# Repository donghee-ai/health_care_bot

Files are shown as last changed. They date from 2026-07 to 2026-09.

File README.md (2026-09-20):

# health_care_bot — UNO Q Health Coach Robot

> 한국어: [`README.md`](README.md)

A health coach robot running as a **single Docker container, single process** on an
Arduino UNO Q (Qualcomm Dragonwing QRB2210, quad-core Cortex-A53 + STM32U585).

It watches your posture through a camera and **counts your reps**, **follows you with a
PTZ gimbal**, and **serves the mobile web app** — all from the same process.

<table>
<tr>
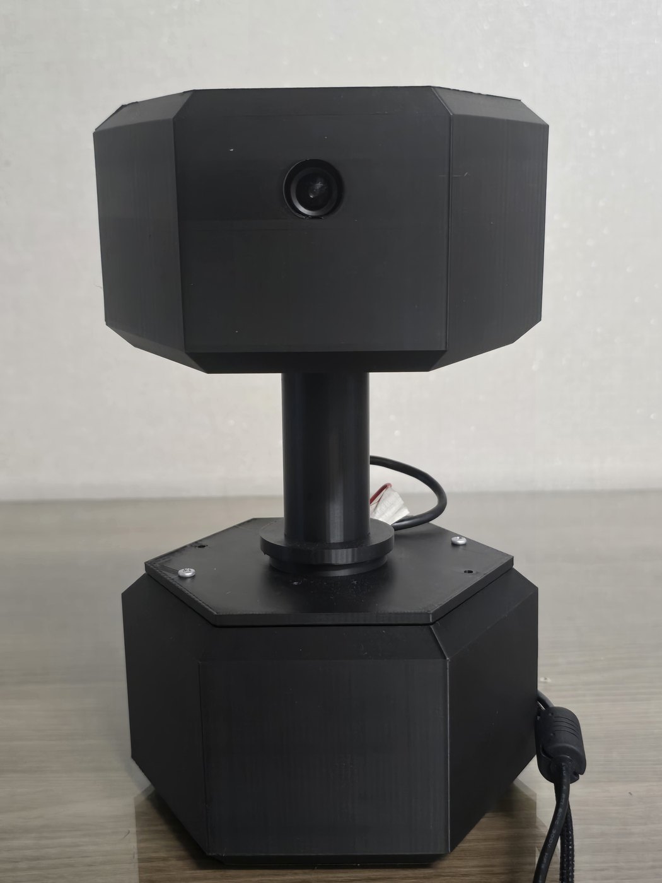
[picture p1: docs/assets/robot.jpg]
The gimbal housing — head holding the camera and pitch motor, hexagonal base holding the yaw motor
<td colspan="2" align="center"><br>
<sub><b>Gimbal housing v8.43</b> · <b>Head</b>: camera + pitch motor (ID=2) · <b>Base</b>: yaw motor (ID=1) + UNO Q, powered hub, servo adapter<br>Both servos sit on one daisy-chained bus</sub></td>
</tr>
<tr>
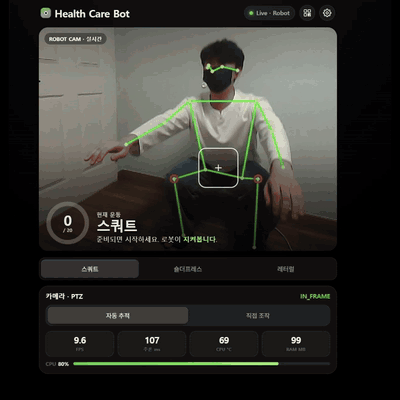
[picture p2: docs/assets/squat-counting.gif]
Squat counting
<td width="50%"><br>
<sub><b>Squat</b> — knee angle 100°↔140° · counter 0→3</sub></td>
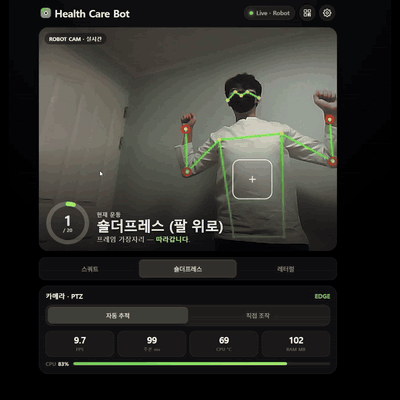
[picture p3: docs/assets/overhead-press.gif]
Overhead press counting
<td width="50%"><br>
<sub><b>Overhead press</b> — shoulder elevation 60°↔140° · 1→3</sub></td>
</tr>
<tr>
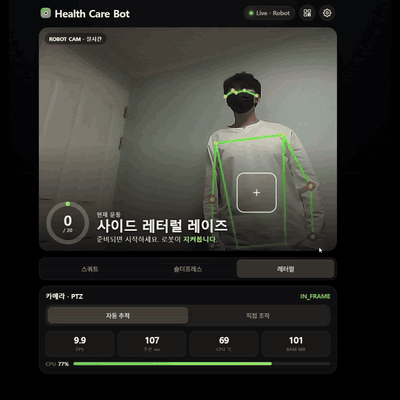
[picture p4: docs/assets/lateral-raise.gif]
Side lateral raise counting
<td width="50%"><br>
<sub><b>Side lateral raise</b> — same angle, 35°↔80° · 0→2</sub></td>
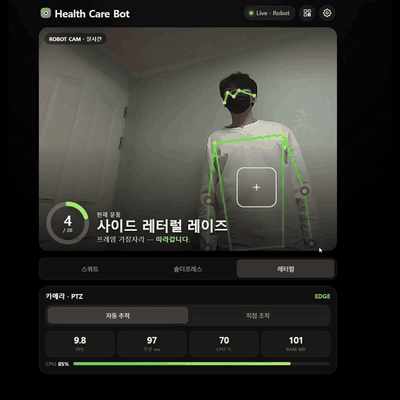
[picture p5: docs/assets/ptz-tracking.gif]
PTZ auto-tracking
<td width="50%"><br>
<sub><b>PTZ auto-tracking</b> — the gimbal pans to follow (watch the background change) · reacquires after the subject leaves frame · <code>EDGE</code>↔<code>IN_FRAME</code></sub></td>
</tr>
<tr>
<td colspan="2"><sub>All four are screen recordings of <code>:8080/app</code> with <b>no speed-up</b> — every 4th frame of a 30 fps capture, played at 7.5 fps, which is real time.
The <b>9.7 FPS · 96 ms · 69 °C · CPU 84 %</b> visible on screen are the live measurements from that moment, matching the table in §9.</sub></td>
</tr>
</table>

> **Documentation note** — This README is the entry point. The detail lives in
> `docs/00`–`docs/09`, **written in Korean**. Their tables, numbers, API schemas and
> command lines are readable without Korean, and the section numbers cited here match.

> **Sister repo** — The MoveNet Thunder INT8 model this robot uses came from
> [`donghee-ai/unoq-edge-ai-lines`](https://github.com/donghee-ai/unoq-edge-ai-lines),
> which measured Vision · Pose · ASR on the same NPU-less UNO Q using CPU only. This repo
> is the product line built from its Pose assets.

---

## 1. What actually runs

| # | Feature | Implementation | Status |
|---|---|---|---|
| 1 | **Squat** counting | knee angle hip-knee-ankle, hysteresis 100°↔140° | works (thresholds still need field tuning) |
| 2 | **Overhead press** counting | shoulder elevation elbow-shoulder-hip, 60°↔140° | works (same) |
| 3 | **Side lateral raise** counting | same shoulder elevation angle, 35°↔80° | works (same) |
| 4 | **PTZ auto-tracking** | two ST3215 bus servos, per-exercise upper/lower-body framing + inertial recovery on loss | verified on hardware |
| 5 | **Web app** (`:8080/app`) | live MJPEG + counters + PTZ control + telemetry | verified on hardware |
| 6 | **Guard mode** | a fourth mode, separate from exercise. Homes immediately on entry → arms after 5 s → on person detection, tracks and captures automatically (`captures/`) → returns home after 10 s with no detection. Manual capture and a photo gallery are available from the web UI | verified on hardware |
| 7 | **Remote access** (Tailscale Funnel) | reach `/app` from outside the local Wi-Fi | verified on hardware (§3.2) |

**Exercises are not classified automatically.** All three are performed facing the camera
while standing, so body orientation cannot separate them — you pick the exercise in the web
UI (`POST /api/mode`). All three counters stay alive simultaneously, so switching modes
preserves each count.

> Push-ups were **removed** on 2026-07-26 — the arms bend along the camera's depth axis, so
> a 2D pose estimator smears the elbow angle. Rationale:
> [`docs/04_algorithm_exercise.md`](docs/04_algorithm_exercise.md) §7.

---

## 2. Architecture at a glance

```
[USB camera] --(FrameGrabber on its own thread: keeps only the newest frame)-->
      |
      v
[MoveNet Thunder INT8 / ai-edge-litert, 256x256 letterbox, 4 threads]
      |
      +--> 17 keypoints (y, x, conf)
             |
             +--> angles.py        knee / shoulder-elevation angles
             |      v
             |    exercise_counter.py   RepCounter (hysteresis + dwell) --> rep++
             |
             +--> ptz_controller.py  target point -> sector/deadzone decision -> deg/s control
             |      v
             |    st3215_bus.py (pyserial, 1 Mbaud, half-duplex)
             |      v
             |    [Bus Servo Adapter] -> [yaw ST3215 ID=1] -> [pitch ID=2]  (daisy chain)
             |
             +--> http_server.py   MJPEG + stats.json + /api/* + /app static serving
                    v
                  browser at http://<UNO_Q_IP>:8080/app
```

**Linux drives the servos directly — not through the MCU.** The ST3215 bus servo adapter
hangs off a USB hub on the UNO Q, and Linux (pyserial) talks to it. `ptz/sketch/health_care_ptz.ino`
is a leftover from the earlier MCU-mediated design and **is not used at runtime.**

Detail: [`docs/01_architecture.md`](docs/01_architecture.md)

---

## 3. Quick start

### 3.1 On the device (UNO Q) — normal operation

```bash
ssh arduino@192.168.0.50              # private LAN; get credentials from the device
cd ~/health_care_bot
bash docker/run.sh                    # auto-detects camera/servo nodes and starts
```

Open `http://192.168.0.50:8080/app` — PTZ control works immediately (control is shared).

Stop with `docker stop health-care-bot`.

> **Check before running** — `/dev/videoN` and `/dev/ttyACM*` numbers **change on every
> boot.** `run.sh` finds them by name, but always read the `camera:` / `serial:` lines in
> the startup log. Override manually with `CAMERA_DEV=/dev/video2 bash docker/run.sh`.
>
> **The IP is DHCP and can change when the router reboots** (it actually moved `.45`→`.50`
> on 2026-08-08). If it does not respond, rescan with `arp -a` or a ping sweep. See
> [`08_troubleshooting.md`](docs/08_troubleshooting.md).

### 3.2 Remote access — from outside the local Wi-Fi (Tailscale Funnel)

Set it up once; afterwards `docker/run.sh` alone opens remote access.

```bash
# once — install Tailscale on the device and log in
curl -fsSL https://tailscale.com/install.sh | sh
sudo tailscale up                     # open the printed URL on a phone/PC to authenticate

# only when needed — turn the public URL on/off (both need sudo; run over SSH)
sudo tailscale funnel --bg 8080
sudo tailscale funnel --https=443 off   # always turn this off when the demo ends
```

External URL: `https://<device>.<tailnet>.ts.net/app` — find the real address with
`tailscale status` on the device (not written here; this repo is public).
Between Tailscale devices without Funnel, use the UNO Q's Tailscale IP (`tailscale ip -4`).

> **This app has no real authentication beyond one PIN (default `1234`).** While Funnel is
> on, anyone with the link can see the camera, drive the PTZ, and browse guard-mode
> photos — use it only while showing a demo, and never leave it exposed.
>
> **FPS drops as stream viewers accumulate** — ~11.3 FPS with no viewer, ~10 with one, down
> to ~8 with two (e.g. PC + phone), measured. The cause is Python GIL thread contention plus
> encryption overhead when remote. The practical mitigation is lowering `--jpeg-quality`.

### 3.3 Development PC — servo test over direct serial

```powershell
cd C:\Project\health_care_bot

# full run (web app + counting + PTZ)
py -3.14 src/main.py models/movenet_thunder_int8.tflite --camera 0 --serial COM9 --serve 8080

# PTZ tracking alone (OpenCV window)
py -3.14 scripts/ptz_camera_track.py --port COM9 --camera 0 --drive
```

**Use `py -3.14`** — the Anaconda `base` environment on this PC has no `cv2`. The servo port
is **COM9** (CH343, 1,000,000 baud), and **without external servo power (6–12.6 V) the port
opens but every ID stays silent.**

### 3.4 Model setup — usually unnecessary

`models/movenet_thunder_int8.tflite` (7.1 MB) is **committed to this repo**, so a clone has
it already. You only need the script below when refreshing the model from the sister repo.

```bash
bash scripts/copy_model.sh    # ../unoq-companion-robot/pose/models/ -> models/
```

---

## 4. Layout

```
health_care_bot/
├── README.md / README_en.md    entry point (Korean / English)
├── THIRD_PARTY.md              third-party attribution (fonts, model, protocol)
├── src/                        runtime (what the container executes)
│   ├── main.py                 entry point: loop + CLI + telemetry
│   ├── pose_utils.py           keypoint constants / letterbox / centroid helpers / draw
│   ├── angles.py               knee_angle, shoulder_elev_angle, pick_angle
│   ├── exercise_counter.py     RepCounter + Squat/OverheadPress/LateralRaise
│   ├── ptz_controller.py       PTZ tracking + loss recovery + direct servo control
│   ├── st3215_bus.py           low-level ST3215 protocol driver
│   ├── http_server.py          MJPEG + stats.json + /api/* + /app + /captures/*
│   ├── app_state.py            session state + operator PIN control lock + guard state
│   └── guard_capture.py        guard mode: person decision + JPEG write + log
├── captures/                   guard-mode output (jpg + guard_log.jsonl) — gitignored
├── web/
│   ├── app/index.html          ★ the UI served at /app — self-contained, edited directly
│   ├── src/                    Vite + React design studies — archived, not served
│   └── dist/                   build output of the above — gitignored, /app works without it
├── docker/                     Dockerfile · requirements.txt · run.sh
├── models/                     movenet_thunder_int8.tflite
├── scripts/                    benchmarks and tools (not runtime)
├── ptz/sketch/                 MCU sketch — unused (MCU track on hold)
├── 3d_model/                   gimbal housing (source · 3mf · stl · validation · preview)
├── docs/                       see §5
└── backup/                     five restore points
```

---

## 5. Document map

All documents below are in Korean.

| # | Document | Contents |
|---|---|---|
| 00 | [`00_project_blueprint.md`](docs/00_project_blueprint.md) | blueprint — purpose, measured status, verification state, doc map |
| 01 | [`01_architecture.md`](docs/01_architecture.md) | processes/threads, module boundaries, state ownership, degrade paths |
| 02 | [`02_http_api_and_stats.md`](docs/02_http_api_and_stats.md) | HTTP API contract + full `stats.json` schema |
| 03 | [`03_algorithm_ptz_tracking.md`](docs/03_algorithm_ptz_tracking.md) | PTZ control law + inertial loss recovery + tuning |
| 04 | [`04_algorithm_exercise.md`](docs/04_algorithm_exercise.md) | per-exercise angles, counting state machine, failure modes |
| 05 | [`05_web_ui_fluid.md`](docs/05_web_ui_fluid.md) | web UI (Fluid) — screens, controls, deployment |
| 06 | [`06_hardware_calibration.md`](docs/06_hardware_calibration.md) | current hardware values + calibration/reassembly procedure |
| 07 | [`07_runbook.md`](docs/07_runbook.md) | run/deploy runbook (device and PC) |
| 08 | [`08_troubleshooting.md`](docs/08_troubleshooting.md) | symptom → cause index |
| 09 | [`09_performance_roadmap.md`](docs/09_performance_roadmap.md) | measured performance + prioritized next steps |
| — | [`docs/history/`](docs/history/) · [`docs/issues/`](docs/issues/) | append-only records — one event per file |

---

## 6. CLI options (the ones you actually use)

Full list: `python3 src/main.py --help`.

| Flag | Default | Meaning |
|---|---|---|
| `--mode` | `squat` | `squat` / `overhead` / `lateral` / `guard`. Changed live via `/api/mode` |
| `--camera` | `0` | `/dev/videoN` index |
| `--serial` | (none) | servo bus port. **Omitting it degrades to PTZ disabled** |
| `--pitch-sign` / `--yaw-sign` | `-1` / `1` | direction correction after reassembly (fixed 2026-08-06). `docker/run.sh` exposes these as `PITCH_SIGN` / `YAW_SIGN` |
| `--serve` | `0` | HTTP port (0 = off) |
| `--conf` | `0.3` | keypoint confidence threshold |
| `--side` | `better` | left/right angle selection: average if both visible, otherwise the visible one |
| `--squat-down-th` / `--squat-up-th` | 100 / 140 | squat thresholds |
| `--overhead-down-th` / `--overhead-up-th` | 60 / 140 | overhead press thresholds |
| `--lateral-down-th` / `--lateral-up-th` | 35 / 80 | lateral raise thresholds |
| `--min-dwell-ms` | `200` | minimum hold time after a state transition |
| `--idle-skip-draw` | off | skip draw+encode when no stream viewer (compute-focused mode) |
| `--sector-side` | `1/6` | side sector width → keeps a central 4/6 band |
| `--pitch-target-y` / `--pitch-deadzone` | 0.62 / 0.20 | lower-body (squat) framing |
| `--track-scale` / `--both-knee-scale` | 0.5 / 0.5 | tracking speed multipliers (1/4 total when both knees are visible) |
| `--frame-out-grace` | `15` | frames without detection before LOST |

PTZ parameter meanings and tuning: [`docs/03_algorithm_ptz_tracking.md`](docs/03_algorithm_ptz_tracking.md) §11.

---

## 7. Safety and operating rules

- **Never touch servo EEPROM while torque is on.** Changing `Homing_Offset` with torque
  enabled makes the servo physically rotate to its old `Goal_Position` — this mistake has
  already **broken a 3D-printed part**. Always calibrate with
  `scripts/calibrate_st3215.py calibrate`, which handles torque off → recompute → goal sync
  → torque on. Detail: [`docs/issues/2026-07-17_01`](docs/issues/2026-07-17_01_homing_offset_wrong_sign_bit_caused_physical_snap.md)
- **Emergency stop**: from another terminal, `py -3.14 scripts/calibrate_st3215.py --port COM9 stop`
- **Measured range of motion** (2026-07-17): yaw (ID=1) 180° ±90°, pitch (ID=2) 180° ±30°.
  The soft limits in code (`yaw_min/max`, `pitch_min/max`) are exactly these. If you change
  the mechanism, re-measure per [`docs/06_hardware_calibration.md`](docs/06_hardware_calibration.md) §4.
- **Rotation speed is fixed at 569 tick/s (≈50 deg/s)** — including while tracking. This is
  a pinch-safety limit; do not raise it.
- **ST3215 servos all ship with ID 1** — assign yaw=1 / pitch=2 individually before chaining
  them. ID changes take effect **immediately** (unlike the generic SDK docs claiming a power
  cycle is needed): [`docs/issues/2026-07-16_01`](docs/issues/2026-07-16_01_servo_id_change_takes_effect_immediately.md)
- **HTTP has no authentication.** Only operator mutations are gated by a PIN-based control
  lock; reads and the stream are unauthenticated. **Do not expose beyond the local LAN.**
  The default PIN is `1234` and can be changed **without editing code** via the
  `HCB_OPERATOR_PIN` environment variable (`docker/run.sh` passes it through):
  `HCB_OPERATOR_PIN=8317 bash docker/run.sh`. When changed, `/app` asks for the PIN once and
  remembers it in the browser. **Tailscale Funnel (§3.2) is no exception to this rule.**
- **The UNO Q's USB host VBUS is off** — bus-powered hubs and devices are not enumerated.
  A **self-powered (externally powered) USB hub is mandatory.** If the camera *and* the servo
  are both missing, suspect hub power before the individual devices.

---

## 8. Traps we keep stepping on

| Trap | Summary |
|---|---|
| Device node numbers | `/dev/videoN` and `ttyACM/ttyUSB` change on every boot. Identify **by name**, never hard-code a number |
| argparse ↔ run.sh drift | Changing `--mode` choices means updating the hard-coded args in `run.sh` **and the Dockerfile CMD**. `--rm` means nothing survives in `docker logs` |
| Phone cannot connect | `ERR_ADDRESS_UNREACHABLE` means the phone's **randomized MAC**, not a server fault |
| `cv2.CAP_PROP_BUFFERSIZE` | The driver ignores it. Solved with `FrameGrabber` (newest frame only) |
| `adb push` | Git Bash rewrites paths and fails silently → **use PowerShell**. `rm -rf` the remote directory first, or you get nested `src/src/` |
| cp949 console crash | Using characters like em-dash or ⚠ **in code or comments** raises `UnicodeEncodeError` on a Windows console |
| Hard-coded API port in the frontend | Pinning `location.hostname:8080` breaks every request behind a reverse proxy or tunnel (Tailscale Funnel does not use port 8080 externally). Use `location.origin` |
| Static QR image for mobile access | The IP is DHCP, so a pre-rendered QR never updates. Re-encode from `location` in the browser every time (`qrSvg()`) |
| `docker/run.sh` dying silently without a tty | `-it` was hard-coded, so non-interactive SSH failed instantly with `the input device is not a TTY` (and `--rm` left no log). Now detects tty and applies it conditionally |
| "PC works, only the phone fails" is not proof against wireless isolation | If the PC is actually on Ethernet it never hits client isolation in the first place. Check the real route first (`Find-NetRoute` on Windows) |
| Automatic and manual triggers sharing a cooldown | The guard-mode "capture now" button shared the auto-detection cooldown, so it was silently swallowed while a person stayed in frame. Manual triggers now ignore the cooldown |
| Docker images filling the ROOT partition | `/var/lib/docker` lives on ROOT, so repeated rebuilds pile up unused layers. Reclaim with `docker image prune -a` (check the list first — it can remove other projects' images) |

Full index: [`docs/08_troubleshooting.md`](docs/08_troubleshooting.md).

---

## 9. Performance (measured)

| Item | Value | Note |
|---|---|---|
| Inference FPS | ~11.4 | **invoke-bound**. Encoding on/off makes almost no difference (with no viewer) |
| Loop latency | ~90 ms | grab → invoke → draw → encode, serial |
| 1 concurrent viewer | ~10 FPS | one extra delivery thread → GIL contention (local or remote alike) |
| 2 concurrent viewers (PC + phone) | ~8 FPS | thread contention, plus Tailscale encryption when remote |
| CPU | ~83 % (of 4 cores = 100 %) | already in the warning band, 17 % left |
| CPU clock | 2016 MHz on all cores = maximum | no governor headroom left |
| Temperature | 51–73 °C | below throttle |

The only large lever for FPS is an **NPU/DSP delegate** (Hexagon HTP · QNN/LiteRT) — this
CPU lacks `asimddp` (INT8 dot product), so it cannot use fast INT8 kernels.

---

## 10. Model / third-party assets

> **This repo's own license is not decided yet.** While there is no LICENSE file, copyright
> remains with the author (no permission granted for redistribution or commercial use).

- Inference model: **MoveNet Thunder INT8** (`models/movenet_thunder_int8.tflite`, 7.1 MB) —
  reused from the Pose line. **Committed to the repo**, so a clone can run immediately.
- Typefaces (Pretendard, Gabarito) are **SIL OFL 1.1**, and the license copies OFL requires
  are bundled under `web/public/fonts/licenses/`.

**The full list of third-party work redistributed here, with the attribution each license
requires, is in [`THIRD_PARTY.md`](THIRD_PARTY.md).**

---

**Author**: DongHee Kim (Hansung University)

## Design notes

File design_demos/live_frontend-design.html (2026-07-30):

UNO·Q HEALTH CARE BOTFIELD OPTICS

Connecting

00:00:00

CAM 01 · FOV 60°

PAN +000.0°
TILT +00.0°
ACQUIRING…

▶ 카메라 시야 열기

AUTO SQUAT PUSH-UP

현재 감지 · Tracking rep

SQUAT

0/ 20

Auto-trackLOCKED

Servo pan/tilt0.0 / 0.0

Track state—

Inference— FPS

>>

로봇에 연결하는 중…

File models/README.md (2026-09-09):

# models/

추론 모델 자산. **`movenet_thunder_int8.tflite`는 git에 포함되어 있다** — clone하면
바로 쓸 수 있다. 출처·라이선스 표기는 [`../THIRD_PARTY.md`](../THIRD_PARTY.md) §2.

자매 리포에서 모델을 갱신할 때만 아래를 쓴다:

```bash
bash scripts/copy_model.sh
# → models/movenet_thunder_int8.tflite (6.8 MB)
```

## 모델

| 파일 | 용도 | 입력 | 출력 |
|---|---|---|---|
| `movenet_thunder_int8.tflite` | Pose 17 keypoint | uint8 [1,256,256,3] | float32 [1,1,17,3] (y_norm, x_norm, conf) |

원본 자산: `../../unoq-companion-robot/pose/models/movenet_thunder_int8.tflite`.

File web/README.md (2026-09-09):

# `web/` — 두 계층

이 디렉터리에는 **성격이 다른 두 가지**가 같이 있다. 헷갈리기 쉬우므로 먼저 구분한다.

| | 경로 | 정체 | 서빙됨? | git |
|---|---|---|---|---|
| **배포본** | `app/index.html` | 자체포함 정적 HTML 1개 (애플 "Fluid") | **예 — `/app`** | 커밋됨 |
| 보관 계층 | `src/` | Vite + React PWA 시안 6종 (CALM/PULSE/AURORA/CORE/CARE/LIVE) | 아니오 | 커밋됨 |
| 빌드 산출물 | `dist/` | 위 시안을 `npm run build`한 결과 | `/app/assets/*`만 | gitignore |

## 배포본 (`app/index.html`)

로봇의 `/app`이 보여주는 화면이다. **HTML·CSS·JS가 전부 한 파일에 인라인**되어 있고
외부 폰트·CDN·번들러를 쓰지 않는다 (로봇은 LAN 전용이라 외부에 나갈 수 없다).

- 고칠 때는 **이 파일을 직접 고친다.** 빌드 단계가 없다.
- 빌드가 없다는 건 문법 오류를 잡아줄 단계도 없다는 뜻이다. 올리기 전에 `<script>`
  블록만 떼어 `node --check`로 확인하거나 최소한 브라우저 콘솔을 한 번 열 것.
- 배포: `scp web/app/index.html <device>:~/health_care_bot/web/app/index.html`
  (`http_server`가 매 요청마다 디스크를 읽으므로 컨테이너 재시작 불필요)

화면 구성·조작·배포 절차: [`../docs/05_web_ui_fluid.md`](../docs/05_web_ui_fluid.md)

## React 시안 (`src/`)

2026-07 초 웹앱 방향을 잡을 때 만든 시안 6종이다. **현재 런타임에 쓰이지 않는다.**
다시 볼 일이 생겼을 때만:

```bash
cd web
npm install
npm run build     # -> web/dist/ (배포본을 덮지 않는다)
npm run dev       # 개발 서버. 백엔드는 scripts/mock_serve.py 로 대신할 수 있다
#   VITE_BACKEND_URL=http://localhost:8090 npm run dev
```

> `npm run build`는 **배포본을 건드리지 않는다.** 서버가 `web/app` → `web/dist`
> 순으로 찾기 때문이다. (2026-09-09 이전에는 배포본이 `dist/index.html`에 있어서
> 빌드하면 덮이는 함정이 있었다.)

설계 근거는 [`ARCHITECTURE.md`](ARCHITECTURE.md), 서체·색 결정은 [`DESIGN.md`](DESIGN.md).

## 폰트

`public/fonts/`의 Pretendard 서브셋은 `scripts/subset_pretendard.py`로 생성한다
(원본은 `fonts-src/`). 배포본은 시스템 폰트만 쓰므로 이 폰트들은 React 시안 전용이다.

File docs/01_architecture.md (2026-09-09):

# 시스템 아키텍처

본 문서는 본 라인이 **어떤 단위로 실행되고, 무엇이 무엇에 의존하고, 어떤 상태를 누가
소유하고, 무엇이 고장나면 어떻게 되는지**를 정리합니다. 코드를 고치기 전에 경계와
degrade 규칙을 정확히 알도록 작성합니다.

- HTTP 계약·`stats.json` 스키마: [`02_http_api_and_stats.md`](02_http_api_and_stats.md)
- 추적/카운팅 알고리즘: [`03`](03_algorithm_ptz_tracking.md) · [`04`](04_algorithm_exercise.md)
- 실행·배포 절차: [`07_runbook.md`](07_runbook.md)
- 성능 실측: [`09_performance_roadmap.md`](09_performance_roadmap.md)

## 0. 한 눈에 — 컨테이너 1개, 프로세스 1개

```
UNO Q (Linux, arm64)
└── docker: health-care-bot:22.04   --net host, -v $PWD:/work
    └── python3 /work/src/main.py            ← 프로세스 딱 하나
        ├── [스레드] FrameGrabber            카메라 read 전용
        ├── [스레드] 메인 추론 루프           invoke → 각도 → 카운터 → PTZ → encode
        ├── [스레드] HTTP accept 루프         http.server + ThreadingMixIn
        └── [스레드] 커넥션당 1개             /stream.mjpg는 연결이 살아있는 동안 점유
```

**웹 프론트엔드에는 런타임이 없다.** 배포 UI(`web/app/index.html`)는 자체포함 정적
HTML 한 장이라 빌드 단계 자체가 없고, 컨테이너는 그 파일을 읽어 내보낼 뿐이다.
React 시안(`web/src/`)을 빌드할 때만 개발 PC에서 Vite를 돌린다 — 컨테이너 이미지에
Node가 아예 없다.

## 1. 스레드 모델

| 스레드 | 소유 | 하는 일 | 주기 |
|---|---|---|---|
| 메인 | `main.py::main` | grab → letterbox → invoke → 각도/카운터 → PTZ → draw → encode → stats | ~90 ms (11 FPS) |
| FrameGrabber | `main.py::FrameGrabber` | `cap.read()`를 계속 돌려 **최신 프레임 1장만 덮어쓰기** | 카메라 속도 (~33 ms) |
| HTTP accept | `http_server.py::start_server` | 소켓 accept → 커넥션마다 스레드 생성 | 이벤트 |
| MJPEG 커넥션 | `_Handler::_stream_mjpg` | 최신 JPEG를 multipart로 밀어냄 + 뷰어 수 카운트 | 30 ms sleep |

메인 루프는 `frame_id`가 그대로면 5 ms 대기하고 넘어간다 — 같은 프레임을 두 번 추론하지
않으면서 바쁜 대기로 코어를 태우지도 않는다.

### 1-1. 왜 캡처 스레드를 분리했나

추론 루프(~90 ms)가 카메라(~33 ms)보다 느리면 드라이버 버퍼에 안 읽힌 프레임이 쌓여
**지연이 계속 누적된다.** `cv2.CAP_PROP_BUFFERSIZE=1`은 V4L2/UVC 드라이버가 무시하는
경우가 흔해 안전장치가 못 된다. 큐가 아니라 "최신 1장 덮어쓰기"로 바꿔 처리 프레임의
나이를 "루프 1회분"으로 고정했다.

> **지연(latency)과 처리량(FPS)은 다른 지표다.** FrameGrabber는 지연만 고쳤고 FPS는
> 그대로다(10.8 ±4 → 동일). 회귀가 아니라 의도된 결과다.
> 상세: [`issues/2026-07-11_04`](issues/2026-07-11_04_camera_buffer_accumulation_causes_growing_latency.md)

## 2. 프레임 파이프라인

```
grabber.latest()            최신 프레임 (BGR, 640x480)
  → letterbox_square(256)   비율 유지 + pad 114 → 256x256
  → BGR2RGB, uint8, [1,256,256,3]
  → interpreter.invoke()    MoveNet Thunder INT8 (4 threads)          ★ 지배적
  → raw [1,1,17,3]
  → unletterbox_kp()        원본 픽셀 좌표계 (y, x, conf) 17개
  ├─ body_orientation()     표시용만 (분류에는 더 이상 안 씀)
  ├─ select_counter(mode)   app_state.get_mode() → squat | overhead | lateral
  ├─ person_center_*()      stats/오버레이용 중심점 (PTZ 추적점과 별개)
  ├─ ptz.set_track_mode(exercise); ptz.update(kp, h, w, now_ms)
  ├─ compute_angle() → counter.update(angle, now_ms) → rep 이벤트
  ├─ draw_pose()            스켈레톤 + 점 + 종목별 강조
  └─ update_live_state()    JPEG 인코딩(q=70) + stats dict 교체
```

### 2-1. 좌표계 주의

MoveNet 출력과 `pose_utils`의 keypoint 배열은 **`(y, x, conf)` 순서**다. 정규화
헬퍼(`*_center_normalized`)는 **`(x_norm, y_norm)`으로 뒤집어서** 반환한다.
PTZ·stats는 정규화 좌표를 쓰고, 그리기는 픽셀 좌표를 쓴다. 두 규약을 섞으면 좌우/상하가
조용히 바뀐다.

### 2-2. 영상에 숫자를 굽지 않는다

FPS/각도/REPS/PTZ는 웹 UI가 `stats.json`으로 이미 표시하므로 `putText` 오버레이를 전부
제거했다. 스켈레톤만 남긴다 — 중복 제거 + 인코딩 비용 절감.

## 3. 모듈 경계와 의존 방향

```
                        main.py  (유일한 조립 지점)
        ┌──────────┬──────────┬─────────┴────┬────────────┬──────────┐
        v          v          v              v            v          v
  pose_utils    angles   exercise_counter  ptz_controller  http_server  app_state
        ^          |            guard_capture     |            |          ^
        └──────────┘                              v            └──────────┘
     (angles가 KP 상수만 참조)              st3215_bus        (init_app 주입)
                                                 |
                                             pyserial
```

원칙:

- **의존은 한 방향으로만 흐른다.** `pose_utils`·`angles`·`exercise_counter`는 순수 계산
  모듈이다. 서보도, HTTP도, 세션도 모른다.
- **`app_state`는 추론과 무관한 순수 상태 객체다.** 모드 전환은 `app_state`에 값을 쓰고,
  추론 루프가 매 프레임 `get_mode()`로 **읽어가는** 방향이다 — 웹이 추론 루프를 호출하지
  않는다.
- `st3215_bus`는 프로토콜만 아는 저수준 드라이버다. 추적 로직이 없어서 벤치
  스크립트(`scripts/test_st3215_serial.py`, `calibrate_st3215.py`)와 공유된다.

### 3-1. 의존성 주입 — `init_app()`

`http_server`는 추론 루프 객체를 **직접 import하지 않는다.** `main.py`가

```python
init_app(ptz=ptz, squat_c=..., overhead_c=..., lateral_c=..., avg_fps_fn=...)
```

로 참조를 주입하고, 핸들러는 모듈 전역에 담긴 그 참조로만 접근한다. 덕분에 카메라·모델
없이 `scripts/mock_serve.py`로 프론트만 검증할 수 있다.

## 4. 상태 소유권

"누가 진짜 주인인가"를 헷갈리면 버그가 난다.

| 상태 | 주인 | 수명 | 비고 |
|---|---|---|---|
| rep 카운터 3개 | `main.py` 지역 변수 | 프로세스 | HTTP에는 참조만 넘김. **3개가 항상 동시에 살아 있다** |
| 서보 목표각 `pan_deg`/`tilt_deg` | `PTZController` | 프로세스 | 서보의 실제 위치가 아니라 **우리가 명령한 각도** |
| 추적 스무딩·복구 단계 | `PTZController` 내부 필드 | 프로세스 | 재검출 시 `_reset_recovery()`로 통째 취소 |
| 세션(mode/status/target) | `app_state._session` | 프로세스 | DB 없음. 재시작 시 초기화 |
| 경비 모드 무장/쿨다운/수동촬영 | `app_state._guard` | 프로세스 | 촬영 **파일**은 `captures/`에 영구 |
| 운영자 제어권 lock | `app_state._control_*` | 60초 (heartbeat 연장) | 재시작 시 초기화 → 좀비 lock이 안 남는 게 오히려 안전 |
| 최신 JPEG / stats | `http_server` 모듈 전역 + `_state_lock` | 다음 프레임까지 | 뷰어 수는 별도 lock |

**모드의 진짜 주인은 `app_state`다.** `--mode` CLI 값은 시작 시 한 번 밀어넣는 초기값일
뿐이고, `--serve`가 켜져 있으면 이후 매 프레임 `app_state.get_mode()`가 이긴다.

## 5. 서보 제어 경로

```
ptz_controller.update()      추적 판정 → 목표각(deg) 결정
  → _write(servo_id, deg)
     → st3215_bus.write_pos_ex(ser, id, deg, speed=569, acc=20)
        → deg * (4095/360) → tick, 0~4095 클램프
        → Feetech STS 패킷 [0xFF 0xFF id len INST_WRITE ADDR_ACC ...] + checksum
        → pyserial write (1 Mbaud) → 어댑터 → 버스 → 서보
```

### 5-1. 코드에 박힌 안전 규칙

1. **소프트리밋 클램프** — 자동 추적·수동 조작·복구 동작 **모든 경로**가
   `_clamp(..., yaw_min, yaw_max)`를 통과한다. 기구부에 부딪히며 밀어붙이는 상황을
   코드 레벨에서 차단.
2. **속도 고정** — `servo_speed=569`(≈50 deg/s)를 모든 명령에 실어 보낸다. 목표각이
   아무리 멀어도 그 속도 이상으로 돌지 않는다(손가락 끼임 방지).
3. **torque ON 순서** — `_torque_on_safe()`가 *현재 위치를 읽어 goal로 먼저 쓴 뒤*
   torque를 켠다. 안 그러면 켜지는 순간 옛 goal로 점프한다.
4. **기동 시 중앙 정렬** — 이전 실행에서 틀어져 있어도 항상 180/180에서 시작하고,
   이동 거리에 비례한 settle 시간을 계산해 대기한다.
5. **EEPROM은 런타임에 절대 안 건드린다.** `Homing_Offset` 조작은 캘리브레이션 스크립트
   전용이다 — torque on 상태에서 바꾸면 실제 회전이 일어나 부품이 깨진다(실기 사고 이력:
   [`issues/2026-07-17_01`](issues/2026-07-17_01_homing_offset_wrong_sign_bit_caused_physical_snap.md)).

## 6. 실패 / degrade 경로

**원칙: 없어도 되는 것이 없으면 기능만 줄이고, 있어야 하는 것이 없으면 즉시 죽는다.**
"반쯤 동작하는데 왜 안 되는지 모르는" 상태를 만들지 않는다.

| 무엇이 없거나 실패 | 결과 | 기동 로그 |
|---|---|---|
| 모델 파일 | **즉시 종료** | `ERROR: model not found` |
| 카메라 열기 실패 | **즉시 종료** | `ERROR: cannot open camera /dev/videoN` |
| HTTP 포트 바인딩 실패 | **즉시 종료** | `ERROR: failed to start HTTP server` |
| `--serial` 미지정 | PTZ **disabled** (추적 계산만) | `[ptz] serial_port 미지정 - disabled` |
| pyserial 없음 | PTZ disabled | `[ptz] st3215_bus 사용 불가` |
| 포트 열기 실패 | PTZ disabled | `[ptz] 포트 열기 실패 (...)` |
| **서보 무응답** (전원 없음/배선) | PTZ disabled | `[ptz] 서보 무응답 (...) - 서보 전원/버스 케이블 확인` |
| 서보 쓰기 오류 (런타임) | 해당 명령만 실패, 카운트 안 됨 | `[ptz] 서보 쓰기 오류` |
| `web/app`·`web/dist` 둘 다 없음 | `/app`이 503 + 힌트 (`web/app`은 커밋되므로 정상 클론에선 발생 안 함) | (요청 시) |
| `captures/` 쓰기 실패 | 해당 촬영만 실패, 경비 모드는 계속 | `[guard]` 로그 없음 |
| `/proc`·`/sys` 없음 (PC) | 텔레메트리 필드가 `null` | 없음 |
| keypoint conf 미달 | 각도 `None` → 카운터는 상태 유지하고 넘어감 | 로그 `L=? R=?` |
| 미검출 지속 | PTZ 복구 사다리 진행 | 로그 `COAST`/`BACK`/`CENTER` |

> **PTZ disabled는 조용하다.** 한 줄 경고 뒤 정상 실행이 계속되므로 "PTZ만 왜 안 되지"로
> 헤매기 쉽다. **기동 로그의 `serial :` 줄을 먼저 보는 습관**이 결국 답이다.

## 7. 구조적 제약

| 제약 | 이유 | 완화 |
|---|---|---|
| FPS ~11 천장 | invoke 바운드, INT8 dotprod 명령 없음 | NPU 델리게이트 (미착수) |
| CPU 여유 17% | 추론+인코딩이 대부분 사용 | 추가 워크로드는 이 여유를 나눠 써야 함 |
| 세션·제어권이 재시작 시 소실 | in-memory, DB 없음 | 시연 성격상 허용 |
| 다중 동시 접속 미검증 | `/stream.mjpg`가 커넥션당 스레드 1개를 영구 점유 | 뷰어 수 실측 안 됨 |
| 500 ms 폴링 지연 | `http.server`와 WebSocket 궁합이 나쁨 | 필요해지면 FastAPI+SSE |
| **서보 실제 위치를 안 읽는다** | 매 프레임 read하면 버스 왕복이 늘어남 | 목표각과 실제각이 어긋나도 감지 못 함 |
| MCU 미사용 | raw serial 경로 없음 + 배선 불가 | 보류 |

### 7-1. 코드에 남은 낡은 것 (동작에 영향)

- ~~`docker/Dockerfile`의 `CMD`가 오래됐다~~ — `--mode auto`라 `run.sh` 없이
  `docker run`만 하면 `invalid choice: 'auto'`로 즉시 종료됐다.
  **2026-09-09에 `--mode squat`으로 정정**(run.sh가 넘기던 값과 동일).
- **`st3215_bus.py::set_id` docstring**이 "실제 반영은 전원 재투입 후"라고 적고 있는데,
  실기에서는 **즉시 반영**된다
  ([`issues/2026-07-16_01`](issues/2026-07-16_01_servo_id_change_takes_effect_immediately.md)).
- ~~`pose_utils.py`·`exercise_counter.py`·`angles.py`·`main.py`·`Dockerfile` 주석의
  "squat + pushup" 옛 표현~~ — **2026-09-09 정리**. `angles.py`의
  `classify_orientation`은 pushup 시절 유물이지만 함수 자체가 아직 쓰이므로
  docstring에 그 경위를 남겨뒀다.

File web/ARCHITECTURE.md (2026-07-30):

# Health Care Bot Live — 아키텍처 & 설계 근거

이 문서는 "무엇을 만들었나"가 아니라 **"왜 이렇게 만들었나"**를 남긴다. 구현
상세와 실행 방법은 [`APP_GUIDE.md`](../APP_GUIDE.md), 기획 원안은
[`APP_PLAN.md`](../APP_PLAN.md) / [`health_care_bot_mvp_screen_plan.md`](../health_care_bot_mvp_screen_plan.md)
참고.

## 1. 전체 데이터 흐름

```
[React SPA (정적 빌드, web/dist)]
        │  fetch('/stats.json')  500ms polling
        │  <img src="/stream.mjpg">
        │  fetch('/api/*', POST)
        ↓
[src/http_server.py — Python stdlib http.server]
        │  기존 추론 루프(main.py)가 update_live_state()로 채워주는
        │  전역 상태를 그대로 읽어서 JSON/정적파일/멀티파트로 응답
        ↓
[src/app_state.py]  세션 상태 + PIN 제어권 lock (in-memory, DB 없음)
[src/ptz_controller.py]  manual_pan/tilt/center + auto_track 토글
```

프론트/백엔드는 별도 서버가 아니라 **하나의 Python 프로세스**가 전부
서빙한다. UNO Q에는 컨테이너 하나, 프로세스 하나만 뜬다.

## 2. 왜 네이티브 앱이 아니라 PWA(모바일 웹앱)인가

- 시연 목표가 "QR 스캔 후 3초 안에 접속"이다. 네이티브 앱은 설치 과정 자체가
  이 목표와 충돌한다.
- 이미 `stream.mjpg` + `stats.json`을 제공하는 HTTP 서버가 있었다 —
  네이티브로 가면 이 자산을 버리고 새 프로토콜을 짜야 한다.
- 관람객/운영자 둘 다 브라우저만 있으면 되므로 Android/iOS 배포 파이프라인이
  필요 없다.

## 3. 왜 Bluetooth가 아니라 WiFi/HTTP인가

"같은 네트워크에 있어야 한다"는 제약을 없애려고 Bluetooth 전환을 검토했지만
기각했다:

1. **영상 스트리밍이 핵심 기능인데 대역폭이 안 나온다.** BLE는 MJPEG를 실어
   나르기엔 너무 느리고, Bluetooth Classic(SPP)은 그나마 낫지만 브라우저
   API로 접근할 수 없어 네이티브 앱을 새로 짜야 한다 — PWA로 간 이유(§2)와
   정면으로 충돌.
2. **iOS Safari가 Web Bluetooth를 아예 지원하지 않는다.** "QR 스캔 후 설치 없이
   접속"이라는 핵심 목표가 아이폰 사용자 전원에게서 깨진다.
3. **애초에 병목을 안 풀어준다.** 네트워크 의존성 문제의 실체는 "영상을 어떻게
   보여주냐"이지 "명령을 어떻게 보내냐"가 아니다. PTZ 명령 같은 저대역폭
   채널만 Bluetooth로 뺀다 해도 영상은 여전히 WiFi가 필요해서 원래 고민이
   그대로 남는다.

네트워크 의존성 자체는 인정하는 제약이고, 완화책은 §9에 정리.

## 4. 왜 Node/FastAPI가 아니라 기존 `http.server` 확장인가 (1차 구현)

- `docker/Dockerfile`에 Node가 없다 — 프론트 빌드는 호스트(개발 PC 또는
  디바이스 콘솔)에서 한 번 하고, 컨테이너는 `web/dist` 정적 파일만 볼륨
  마운트로 읽는다. 런타임에 Node/Vite가 디바이스에서 도는 일은 없다.
- 기존 `http_server.py`가 이미 MJPEG + JSON을 서빙하고 있었다. API 몇 개
  (`POST /api/*`) 추가하는 것으로 충분한데 FastAPI/uvicorn을 새로 얹으면
  의존성만 늘어난다. `APP_PLAN.md` §8.2도 1차는 `http.server` 유지, 2차에
  FastAPI 전환을 권장했다.
- 결과적으로 웹앱 레이어가 추가한 런타임 비용은 정적 파일 응답 + 저빈도
  JSON API 라우팅뿐이다 — 카메라 캡처/추론/인코딩 같은 무거운 작업은
  웹앱 이전과 완전히 동일하다.

## 5. 왜 WebSocket/SSE가 아니라 500ms polling인가 (1차 구현)

- 상태 갱신 목표가 250–500ms면 충분하다고 `APP_PLAN.md` §6.1에 이미 정의돼
  있다 — 실시간 커넥션이 주는 이점(수 ms 단위 지연 감소)이 이 앱의 요구사항
  대비 과설계다.
- `http.server`는 커넥션을 오래 붙잡는 WebSocket과 궁합이 안 좋다
  (`ThreadingMixIn` 기반이라 스레드 하나가 커넥션 하나를 통째로 점유).
  polling(JSON API 계층)은 요청-응답이 즉시 끝나 스레드 회전이 빠르다.
- 2차 구현(FastAPI 전환 시)에서 SSE/WebSocket으로 옮기는 걸 `APP_PLAN.md`가
  이미 로드맵에 넣어뒀다 — 지금 안 하는 이유가 "못 해서"가 아니라 "아직
  필요 없어서".
- 다만 이건 `/stats.json`·`/api/*` 같은 짧은 요청-응답 계층에만 해당하는
  이야기다. `/stream.mjpg`는 정의상 커넥션을 계속 붙잡는 스트림이라 이미
  스레드 하나를 영구 점유하고 있고, 이건 polling을 쓰든 WebSocket을 쓰든
  똑같이 존재하는 비용이다. 뷰어가 많아졌을 때 이게 실제로 버티는지는
  검증 전 — §9 참고.

## 6. 왜 풀 인증이 아니라 PIN 기반 제어권 lock인가

- 배포 환경이 로컬 LAN 전용으로 명시돼 있다 (`README.md`, `APP_PLAN.md` §11) —
  외부 인터넷에 노출되지 않는다는 전제.
- 위협 모델이 "악의적 공격자"가 아니라 "관람객이 실수로 다른 사람이 조작
  중인 PTZ를 건드리는 것" 정도다. PIN + 60초 lock + heartbeat 연장이면
  충분하고, 세션/유저 관리, 비밀번호 해싱, JWT 같은 걸 넣는 건 과설계.
- 상태도 DB 없이 `app_state.py`의 in-memory dict + `threading.Lock` 하나로
  충분 — 디바이스가 재시작되면 lock도 같이 초기화되는 게 오히려 안전하다
  (좀비 lock이 안 남음).
- 단, 이 lock이 푸는 건 "PTZ를 누가 조작하냐"는 충돌뿐이다. "여러 명이
  동시에 접속했을 때 서버가 부하를 버티는가"라는 더 넓은 다중 접속 문제는
  아직 별개로 미해결 상태다 — §9 참고.

## 7. 왜 CSS 변수 테마가 아니라 시안별 독립 폴더인가 (2026-07-20 변경)

> 이전에는 `:root`의 CSS 변수를 치환하는 단일 테마 시스템이었다
> (`index.css` + `hooks/useTheme.ts`). 2026-07-20 재설계에서 이 구조를
> 버렸다. 설계 근거 전체는 [`DESIGN.md`](./DESIGN.md).

변수 치환은 **같은 레이아웃에 색만 바꿀 때** 유지보수 비용이 0에 가깝다.
하지만 이번 요구는 "완전히 다른 느낌의 시안 4개"였고, 그건 색 문제가
아니라 **정보 구조·밀도·조판이 통째로 다른 문제**였다.

- INSTRUMENT는 헤어라인 격자에 수치를 빽빽이 깔고, CALM은 링 하나에
  숫자 한 개만 놓는다. 같은 마크업에 변수만 바꿔서 나올 수 있는 차이가
  아니다.
- 변수로 억지로 묶었다면 모든 컴포넌트가 4가지 분기를 품게 되고,
  시안 하나를 고치다 나머지 셋이 깨지는 구조가 된다.

그래서 **시안마다 `.tsx` + `.css`를 통째로 소유**하고 서로 아무것도
공유하지 않게 했다. lazy로 나뉘어 있어 보고 있는 시안의 CSS만 로딩된다 —
네 벌의 CSS가 한꺼번에 들어와 서로 덮어쓰는 사고를 구조적으로 막는다.

공유하는 건 **데이터와 동작뿐**이다. 훅(`useStats`, `useMjpeg`,
`useRepPulse`, `useSeries`, `usePressRepeat`)은 값을 계산하고 상태를
관리할 뿐 마크업을 만들지 않는다. 서버 API 계약도 그대로다.

대가는 CSS 중복이다. 시안을 하나로 확정하고 나면 나머지 셋을 지우면서
회수된다 — 비교 단계에서만 지불하는 비용으로 봤다.

## 7-1. 폰트를 왜 self-host 하는가

로봇은 LAN 전용이라 **구글 폰트 CDN에 나갈 수 없다.** CDN을 쓰면
시연장에서 폰트만 통째로 안 뜨는 사고가 난다.

Pretendard 원본 2.0MB는 "QR 스캔 후 3초"(§2) 목표와 충돌해서,
`scripts/subset_pretendard.py`로 unicode-range 조각을 만든다.
소스에 실제로 쓰는 글자를 모은 우선 조각(`kr-core`)을 맨 앞에 두고
나머지는 안전망으로 뒤에 남긴다 — 모든 글자가 어딘가에는 있으므로
두부(□)가 원천적으로 불가능하다. 실측 226~346 KB / 3~4 요청.

코드포인트 순으로만 쪼갰다가 실패한 기록:
[`docs/issues/2026-07-20_01`](../docs/issues/2026-07-20_01_unicode_range_chunking_by_codepoint_is_useless.md)

## 8. 왜 캡처 스레드를 분리했는가 — 지연(latency)과 처리량(FPS)은 다른 문제

`src/main.py::FrameGrabber`(2026-07-15 추가)는 카메라를 별도 스레드에서
계속 읽어 최신 프레임 1장만 보관하고, 추론 루프는 그 최신 프레임만
가져다 쓴다. 이 수정을 이해하려면 **지연**과 **FPS(처리량)**를 구분해야
한다 — 실측 검증에서 이 둘이 서로 다르게 움직이는 걸 직접 확인했다
(`docs/history/2026-07-15_01_framegrabber_verified_latency_fixed_fps_unchanged.md`).

- **문제였던 것 (지연)**: 카메라가 캡처하는 속도(예: ~33ms/frame)가 추론
  루프 속도(예: ~90ms/frame)보다 빠르면, `cap.read()`를 메인 루프에서
  직접 부를 경우 안 읽힌 프레임이 드라이버 버퍼에 계속 쌓인다.
  `cv2.CAP_PROP_BUFFERSIZE=1`을 걸어놔도 V4L2/UVC 드라이버에 따라 무시되는
  경우가 흔해 안전장치가 못 된다 — 그 결과 화면은 매끄럽게 재생되지만
  실시간보다 계속 뒤처진 프레임을 보여주는(그리고 계속 더 뒤처지는)
  증상이 났다.
- **FrameGrabber가 고친 것**: 큐가 아니라 "최신 프레임 1장 덮어쓰기"
  방식으로 바꿔서, 처리되는 프레임의 나이(age)가 항상 "루프 1회분"으로
  고정되고 더 이상 누적되지 않는다. 사용자 실측 결과 "실시간성이 있다"로
  체감 확인됨.
- **FrameGrabber가 안 고치는 것 (FPS)**: 추론(MoveNet) + pose draw + JPEG
  인코딩 자체의 처리 속도는 그대로다. 이 파이프라인이 루프당 ~90ms
  걸리면, 초당 실제로 처리·전송되는 distinct 프레임 수(=`/stats.json`의
  `fps`)는 여전히 ~11fps 근처다. 배포 후 실측에서 `fps`가 수정 전후로
  **10.8 ±4로 동일**하게 나온 것 자체가, 이 수정이 의도대로 지연만
  고치고 처리량은 안 건드렸다는 증거다 — 회귀가 아니라 예상된 결과.
- **FPS(처리량) 자체를 올리려면** 별도 작업이 필요하다 — 해상도 축소,
  추론 스레드/딜리게이트 튜닝, 인코딩 품질 조정 등. 현재 요구사항 밖이라
  미착수.

## 9. 알려진 제약 & 완화책

| 제약 | 이유 | 완화책 (미구현, 필요 시 추가) |
|---|---|---|
| 같은 WiFi/네트워크에 있어야 접속 가능 | §3 참고 — Bluetooth로도 안 풀리는 문제라 WiFi 유지 | `healthbot.local` mDNS(avahi), 또는 UNO Q 자체 핫스팟(hostapd) — `APP_PLAN.md` §5에 설계는 있으나 코드 미구현 |
| PIN이 평문 하드코딩(`app_state.py::_operator_pin`) | 로컬 LAN 전용 전제, 시연용 최소 마찰 | 시연 전 값 교체 필수. 외부 노출 시나리오가 생기면 `.env` 분리 필요 |
| 500ms polling → 순간 상태는 최대 500ms 지연 | §5 참고, 현재 요구사항엔 충분 | FastAPI + SSE/WebSocket 전환 (`APP_PLAN.md` Phase 3) |
| 세션/제어권 상태가 프로세스 재시작 시 소실 | in-memory, DB 없음 (§6) | 시연 성격상 허용 범위로 판단. 영속화 필요해지면 SQLite 검토 |
| PTZ 직접 제어 지연 목표치(API 응답 100ms, 실제 서보 movement 시작 100–300ms)가 아직 미검증 | 실제 서보가 디바이스에 체결된 적이 없어 `APP_PLAN.md` §6.2/§14의 목표값을 그대로 문서화만 해둔 상태 — 실측 아님 | **추후 모터 실제 체결 후 재측정해서 이 문서와 `APP_PLAN.md` 수치를 갱신할 예정** |
| 다중 동시 접속 처리가 아직 해결되지 않음 — 여러 관람객·여러 운영자가 한꺼번에 붙었을 때의 서버 부하/안정성이 미검증 | `http.server`의 `ThreadingMixIn`이 커넥션(특히 `/stream.mjpg`)마다 스레드를 하나씩 점유하는 구조라 대량 동시 접속 시 성능이 실측된 적 없음 (`APP_PLAN.md` §14 "5명 이상 동시 접속 시 서버 유지" 목표는 아직 검증 전) | **일단은 PTZ 제어권만 PIN 기반 lock으로 운영자 1명에게 위임**(§6)해 "여러 명이 동시에 장비를 조작"하는 충돌만 막아둔 상태 — 동시 접속자 수 자체를 제한하거나 서버 부하를 검증하는 작업은 아직 안 함 |
| FPS(처리량)이 낮음(~10.8 ±4) | §8 참고 — 추론+draw+encode 파이프라인 자체 속도 한계, FrameGrabber는 지연만 고침 | 해상도 축소, 추론 스레드/딜리게이트 튜닝, 인코딩 품질 조정 (미구현) |

## 10. 관련 문서

- **디자인 시안 4종 & 서체·색 결정 근거: [`DESIGN.md`](./DESIGN.md)**
- 실행 방법: [`APP_GUIDE.md`](../APP_GUIDE.md)
- 기획 원안: [`APP_PLAN.md`](../APP_PLAN.md), [`health_care_bot_mvp_screen_plan.md`](../health_care_bot_mvp_screen_plan.md)
- 로봇 본체 아키텍처(추론 루프/PTZ 하드웨어): [`README.md`](../README.md)
- 의사결정 히스토리: [`docs/history/`](../docs/history/)

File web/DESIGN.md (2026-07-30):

# 웹앱 디자인 시안 — CALM (후보)

같은 데이터(스쿼트 카운트 · MoveNet 자세 추정 · UNO Q 상태 모니터링)를
서로 다른 제품처럼 보이게 만든 시안을 처음엔 4종 만들었다.
검토 결과 **CALM 하나만 후보로 남기고 나머지 셋은 삭제**했다.

> **상태: 후보 (2026-07-21).** CALM은 확정된 프로덕션 UI가 아니라 아직
> 검토 중인 후보다. 이전 웹앱은 `backup/web_2026-07-20_pre_redesign/`에,
> 삭제된 시안 3종은 §2의 백업 경로에 그대로 있다.
>
> 이 문서는 **웹 프론트엔드 작업 기록**이다. 추론 루프(MoveNet, 카운터,
> PTZ 제어, `src/*.py`)는 이번 작업에서 전혀 건드리지 않았다.
> 서버 API 계약(`/stats.json`, `/api/*`)도 그대로다.

---

## 1. 보는 방법

```
/app                     CALM (후보)
/app?role=operator       조작 권한까지 (세션 버튼 · PTZ 패드)
/app?demo=1              로봇 없이 둘러보기 (합성 데이터)
```

- 삭제된 시안 주소(`?ui=instrument` 등)는 자동으로 CALM으로 폴백한다.
- 시안 전환 구조(레지스트리 · 피커 · `useVersion`)는 일부러 남겨뒀다 —
  CALM이 "확정 UI"가 아니라 "후보"임을 구조로 드러내고, 후보를 다시
  늘리거나 교체할 때 그대로 쓰기 위함이다. 화면 우상단 **`시안 정보`**
  버튼(또는 키 `v`)으로 현재 후보를 확인할 수 있다.

### 데모 모드

로봇 없이 노트북에서 시안을 검토·발표 리허설할 수 있다. `?demo=1`을
붙이거나, `/stats.json`에 한 번도 못 붙으면 자동으로 켜진다.
**실제 stats가 한 번이라도 도착하면 절대 켜지지 않으므로** 디바이스
동작에는 영향이 없다. 데모일 때는 화면에 항상 표식이 뜬다
(`DEMO` / `견본` / `둘러보기`).

합성 데이터는 실측 범위에 맞췄다 — FPS 10.8, CPU 83%, 스쿼트 주기 3.2초.
카메라 자리에는 MoveNet과 같은 골격을 무릎 각도에 맞춰 그린다.

---

## 2. CALM — 남은 후보

Gentler Streak이 애플 디자인 어워드를 받은 이유가 "못 채운 날을 실패로
만들지 않는 설계"였다는 점을 가져왔다.

| | CALM |
|---|---|
| 성격 | 숨쉬는 코치 |
| 계열 | Gentler Streak · Apple Fitness · Things 3 |
| 바탕 | `#eef2ef` |
| 강조 | 딥그린 `#0f4c3a` · 옐로 `#f2b705` |
| 디스플레이 서체 | Gabarito |
| 모서리 | 14–24px |
| 그림자 | 아주 얕게 |
| 답하는 질문 | "괜찮게 하고 있나" |

- 값이 아니라 **상태**를 먼저 말한다. 장치 수치를 "로봇이 편안하게
  돌아가고 있어요"로 번역해 앞에 두고, 정확한 숫자는 아래 작게 둔다.
- "17회 남았어요"이지 "17회 부족"이 아니다.
- 진척을 애플 피트니스식 **링**으로 그린다. 큰 모서리와 얕은 그림자로
  촉감을 만든다 — 삭제된 세 시안이 전부 각져 있던 것과 대비된다.

### 삭제된 시안 3종 (참고)

CALM을 고르면서 아래 셋은 삭제했다. 되살리려면 백업에서 해당 폴더와
`fonts.css` 항목·폰트 파일을 가져오면 된다
(`backup/web_2026-07-20_pre_redesign/src/versions/`,
`.../public/fonts/`).

| | INSTRUMENT | ALMANAC | STADIUM |
|---|---|---|---|
| 성격 | 정밀 계측기 | 기록하는 종이 | 중계 스코어보드 |
| 계열 | Linear · Vercel · 글래스콕핏 | Oura · 편집 조판 | Strava · Nike · 방송 그래픽 |
| 바탕 | `#0a0b0d` | `#f4f0e6` | `#0b0b0b` |
| 강조 | 라임 `#c8f751` | 벽돌 `#8a3b2c` | 주황 `#ff3b00` |
| 서체 | Spline Sans Mono | Newsreader | Archivo (wght+wdth) |
| 답하는 질문 | "장비가 지금 어떤가" | "오늘 무엇을 했나" | "몇 개 남았나" |

- **INSTRUMENT** — 장식을 걷어내고 수치·단위·상태만 남긴 계기판. 헤어라인
  격자, 깊이 막대의 인정 임계선 눈금, 사람 위치 눈금으로 PTZ 이유 설명.
- **ALMANAC** — 대시보드가 아니라 오늘 자 지면. 제호·2단 조판·그림 설명·
  계측표·판권란. 진척을 눈금자로 그리고 구획은 전부 괘선으로 나눔.
- **STADIUM** — 2~3미터 밖에서 0.3초 안에 읽히는가만 기준. 횟수 숫자
  최대 190px, Archivo 폭 축(wdth 78)으로 좁게 세움, 방송 로워서드 3분할.

---

## 3. 리서치에서 뒤집힌 것들

Playwright로 22개 사이트(WHOOP·Oura·Strava·Linear·Vercel·Eight Sleep·
Nike·Arc 등)의 계산된 스타일을 긁어 팔레트와 서체를 실측했고,
서체·모션·색 체계는 별도로 조사했다. 그 결과 **초기 선택 몇 개가
근거를 잃어서 바꿨다.**

### 서체를 바꾼 이유

| 처음 골랐던 것 | 바꾼 것 | 이유 |
|---|---|---|
| Instrument Serif | **Newsreader** | Instrument Serif는 Space Grotesk·Geist와 함께 2026년 기준 "AI가 만든 티"로 지목되는 조합. Newsreader는 숫자가 기본으로 tabular + lining이라 표에 그대로 쓸 수 있다 |
| Fraunces (후보) | 탈락 | **`tnum` 기능이 아예 없다.** 실시간으로 바뀌는 숫자를 다루는 앱에서 자릿수가 흔들리는 서체는 애초에 후보가 아니다 |
| Anton | **Archivo** | Anton은 단일 굵기. Archivo는 wght+wdth 2축이라 압축 디스플레이와 표제를 파일 하나로 내고, 숫자 기능이 가장 충실하다 |
| Outfit | **Gabarito** | Outfit은 "AI 기본값" 계열로 닳았다 |
| JetBrains Mono | **Spline Sans Mono** | "코드 에디터 폰트"라는 기성 인상이 덜하고, UI용으로 설계돼 셀 폭이 좁다 |

한글은 (삭제된 시안 포함) 전부 **Pretendard**였다. 한국어 UI에서 사실상
표준이고, 여기서 개성을 내려다 가독성을 잃는 건 손해다. 개성은 라틴/숫자
디스플레이 서체 쪽에서 만든다. CALM은 Gabarito를 쓴다.

> 위 표는 4종을 만들 때의 서체 결정 근거다. 삭제 후 실제로 남은 건
> Pretendard + Gabarito뿐이고, Spline Sans Mono / Newsreader / Archivo는
> 백업에만 있다. 결정의 맥락으로 남겨둔다.

### 고친 실제 결함

- **INSTRUMENT 팔레트 대비 미달** — `--ink-3`가 라벨 텍스트 색으로
  18곳에 쓰이는데 대비가 읽기 한계 아래였다. 그리고 `--crit`(위험)이
  `--warn`(주의)보다 어두워서 **가장 급한 상태가 가장 안 읽혔다.**
  둘 다 밝은 쪽으로 올렸다.
- **`ch` 단위 함정** — Pretendard·Inter는 `1ch`가 tabular 자폭보다
  약 3% 좁다. `width: 5ch`로 숫자 칸을 잡으면 조용히 잘린다. 안 썼다.
- **`font-feature-settings` 우선순위** — 이게 `font-variant-numeric`보다
  우선해서, 어딘가에서 한 줄 선언되면 tabular이 무력화된다.
  숫자 요소에 방어적으로 `font-feature-settings: normal`을 걸었다.
- **커닝이 tabular을 깨는 경우** — 일부 서체는 고정폭 숫자에까지
  커닝 페어를 걸어둬서 `"11111"`과 `"00000"`의 폭이 달라진다.
  `font-kerning: none`을 같이 건다.
- **한글 줄바꿈** — 한글 음절은 유니코드상 표의문자로 분류돼, 기본값이면
  브라우저가 아무 음절 사이에서나 줄을 끊는다("한국어를" → "한국/어를").
  한국어는 어절 사이를 띄우므로 이건 그냥 틀린 동작이다.
  `word-break: keep-all`을 전역으로 걸었다.
- **본문 크기** — 한국 정부 디자인 시스템(KRDS) 기준 본문 17px / 행간 150%.
  한글은 같은 판독성에 라틴보다 큰 광학 크기가 필요한데, 한국어 UI에서
  가장 흔한 실수가 행간이 아니라 너무 작게 쓰는 것이다.

### 가변 축을 직접 잡았다

굵기를 400/600/700 같은 토큰 값으로 쓰면 "기본값 그대로"로 읽힌다.
가변 폰트에서만 낼 수 있는 값을 쓴다 — `wght 340`, `390`, `540`,
`580`, `620`, `wdth 78`, `opsz 60/72`. 작은 라벨(12px 이하)에는
**양수** 자간, 큰 숫자에는 음수 자간. 큰 글자 기준 음수 자간을 라벨까지
일괄 적용하는 게 흔한 실수다.

---

## 4. 폰트 로딩

로봇은 LAN 전용이라 구글 폰트 CDN에 못 나간다. CDN을 쓰면 시연장에서
폰트만 통째로 안 뜨는 사고가 난다. **전부 self-host.**

Pretendard 원본은 2.0MB다(한글 음절 11,172자 전부). "QR 스캔 후 3초"
목표와 정면으로 부딪혀서 `scripts/subset_pretendard.py`로 쪼갰다.

- **`kr-core.woff2`** — 소스에 실제로 등장하는 글자만 모은 우선 조각.
  화면에 뜨는 한글은 거의 전부 여기서 해결된다.
- **`kr-NN.woff2`** — 나머지 음절. 문구를 바꿨을 때를 위한 안전망.
  모든 글자가 어딘가에는 있으므로 **두부(□)가 원천적으로 불가능하다.**
- 시안별 디스플레이 서체는 `@font-face`가 실제로 쓰일 때만 받으므로,
  지금 보는 시안의 폰트만 네트워크를 탄다.

폰트를 추가하거나 한국어 문구를 크게 바꿨으면 다시 돌린다:

```bash
cd web && python scripts/subset_pretendard.py
```

원본은 `web/fonts-src/`에 둔다 (`public/`에 두면 dist에 2MB가 그대로 실린다).

### 디스크와 전송량은 다르다

`public/fonts/`는 조각 46개를 합쳐 **디스크에서 4.3MB**다. 하지만
브라우저가 실제로 **전송받는 건 226~346KB**뿐이다 — 나머지는 문구를
바꿨을 때를 위한 안전망이라 평소엔 아무도 받아가지 않는다.

`dist/`는 `.gitignore`돼 있지만 `public/fonts/`는 아니라서, 커밋하면
레포에 4.3MB가 들어간다. 판단이 필요한 지점이다:

- **그대로 커밋** — clone 후 `npm run build`만으로 끝난다(파이썬 불필요).
  가장 안전하지만 레포가 무거워진다.
- **`public/fonts/pretendard/`를 무시** — 레포는 가볍지만 빌드 전에
  `python scripts/subset_pretendard.py`를 반드시 돌려야 하고,
  `fonts-src/`(2MB)는 여전히 커밋해야 한다.

아직 정하지 않았다.

---

## 5. 구조

```
src/
  App.tsx                시안 라우팅 + 단축키
  api.ts, types.ts       서버 계약 (변경 없음)
  base.css               시안이 공유하는 최소한의 바닥
  fonts.css              @font-face 선언 (Pretendard + Gabarito)
  pretendard.css         (생성됨) unicode-range 조각
  hooks/                 동작만 — 생김새는 시안이 소유
    useStats             폴링 + 연결 상태 + 데모 폴백
    useMjpeg             스트림 재연결 · 전체화면
    useRepPulse          "1회 인정" 순간 감지
    usePressRepeat       PTZ 길게 누르기 반복
    useVersion           시안 선택 (URL > 저장값 > 기본)
  components/DemoPose    데모용 합성 골격
  shell/VersionPicker    시안 전환 시트 (후보 목록)
  versions/
    registry.ts          시안 메타 + 공통 props 타입
    calm/                남은 후보 1종
```

**시안끼리 스타일을 공유하지 않는 구조를 유지한다.** 각 시안은 자기
`.tsx` + `.css`를 통째로 소유하고 lazy로 나뉘어, 보는 시안의 CSS만
로딩된다 — 시안이 여럿일 때 서로의 CSS가 한꺼번에 들어와 덮어쓰는 사고를
막던 구조다. 지금은 후보가 하나뿐이지만, 후보를 다시 늘릴 때 그대로
쓰려고 남겨뒀다.

공유하는 건 **데이터와 동작**뿐이다 — 훅은 값을 계산하고 상태를 관리할
뿐 마크업을 만들지 않는다. (`useSeries`는 스파크라인을 쓰던 INSTRUMENT·
STADIUM과 함께 삭제됐다.)

---

## 6. 검증한 것

`npm run build` 통과, 그리고 Playwright로 CALM × 모바일(402px)/
데스크톱(1440px) + 삭제된 시안 URL 폴백을 자동 확인:

- CALM이 **자기 디스플레이 서체(Gabarito)를 실제로 로드**하는지 (폴백 아님)
- 큰 숫자에 **tabular-nums가 걸려 있는지**
- **가로 스크롤이 생기지 않는지**
- 삭제된 시안 주소(`?ui=instrument` 등)가 **CALM으로 폴백**하는지,
  삭제된 시안 루트(`.ins`/`.alm`/`.std`)가 **남아있지 않은지**
- 피커 후보가 **1개**인지, 시트가 열리는지
- 콘솔 에러 없음

### 아직 확인 못 한 것

- **실기에서 안 돌려봤다.** 데모 데이터와 빌드까지만 확인했고,
  UNO Q에 올려 실제 MJPEG 스트림·실제 PTZ 조작으로 검증하는 건 남았다.
- 실제 스트림이 들어왔을 때의 프레임 밀도, 조작 지연, 배터리·발열 영향은
  디바이스에서 봐야 한다.
- 아이폰 사파리 실기 확인이 남았다.

---

## 7. 되돌리기

이전 웹앱은 통째로 백업돼 있다:

```
health_care_bot/backup/web_2026-07-20_pre_redesign/
```

`src/`, `public/`, `dist/`, 설정 파일까지 전부 포함. 되돌리려면
`web/`의 `src`·`public`을 이걸로 덮고 `npm run build` 하면 된다.

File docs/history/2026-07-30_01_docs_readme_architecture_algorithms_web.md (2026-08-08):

# 2026-07-30 — README 최신화 + 상설 문서 3종 신설 (아키텍처 / 알고리즘 / 웹)

## 시점

2026-07-30. 세션 시작 시 핸드오프·docs 전체를 정독한 직후. 문서를 읽는 과정에서
**README가 07-17 상태로 멈춰 있어 사실과 다르다**는 것이 드러나 최신화하고, 그동안
히스토리에만 흩어져 있던 내용을 주제별 상설 문서로 뽑았다.

## 왜

히스토리(`docs/history/`)는 "언제 무엇이 있었나"를 남기는 데는 좋지만, **"지금 어떻게
동작하는가"를 물으면 20개 파일을 순서대로 읽어야** 답이 나온다. 실제로 이번 정독에서
같은 정보가 여러 히스토리에 조금씩 다른 버전으로 흩어져 있는 것을 확인했다
(예: PTZ 관성 튜닝값이 `2026-07-19_02` 요약 블록에는 stale하게 10/0.8로 적혀 있고
본문에는 15/0.9로 적혀 있다).

`exercise_detection.md`가 종목 설계에 대해 이 역할을 이미 하고 있었으므로, 같은 방식으로
**아키텍처·알고리즘·웹**에 상설 문서를 만들었다.

## 무엇을

### 1. `README.md` 전면 최신화

낡아서 **틀린 내용**이었던 것:

- 기능표에 **푸시업**이 남아 있었다(07-26에 삭제됨). 숄더프레스·레터럴이 없었다.
- `--mode auto`(자세 자동 분류)를 문서화하고 있었다 — argparse에서 제거된 값이다.
- 아키텍처 그림이 **서보를 MCU 스케치 경유**로 그려놨다. 실제로는 Linux가 pyserial로
  버스를 직접 구동하고 MCU는 런타임에 쓰이지 않는다.
- `st3215_bus.py`가 `scripts/`에 있다고 적혀 있었다(실제 `src/`).
- 폴더 구조에 `web/`, `docs/`, `design_demos/`, `backup/`, `stl/`이 아예 없었다.

새로 담은 것: 문서 지도, 실측 성능(11.4 FPS invoke 바운드 · CPU 83%), 디바이스/PC
실행법 분리, 실제 argparse 기준 CLI 표, 안전 규칙(VBUS·EEPROM·속도 고정), 함정 요약표.

### 2. `docs/architecture.md` (신규)

"어떤 단위로 실행되고, 무엇이 무엇에 의존하고, 어디서 시간이 들고, 무엇이 고장나면
어떻게 되는가".

- 컨테이너 1 / 프로세스 1 / **스레드 4종** 표 (메인·FrameGrabber·HTTP accept·MJPEG 커넥션)
- 프레임 파이프라인 단계별 + **좌표계 주의**(kp는 `(y,x,conf)`, 헬퍼는 `(x,y)` 반환)
- 모듈 의존 방향 그림 + `init_app()` 주입 구조가 왜 그런지
- **상태 소유권 표** — "모드의 진짜 주인은 `app_state`"처럼 헷갈리는 지점 명시
- 서보 제어 경로 + 코드에 박힌 안전 규칙 5가지
- HTTP 계약 + `stats.json` **전체 스키마**(주석 포함) + 읽을 때 함정
  (`cpu_percent` 첫 응답 `null`, 컨테이너에서도 호스트 전체 부하, `pan_deg`는 목표각)
- **degrade 경로 표** — "없어도 되는 것이 없으면 기능만 줄이고, 있어야 하는 것이 없으면
  즉시 죽는다"는 원칙과 실제 로그 문구
- 성능 실측표 + `--idle-skip-draw` 게이팅 이득
- 구조적 제약 + **코드에 남은 낡은 것** 3건 (아래 "발견" 참고)

### 3. `docs/algorithms.md` (신규)

PTZ 제어와 rep 카운팅의 수식·상태 전이·튜닝값.

- PTZ: 컨벤션 → 목표점 폴백 사슬 → EMA → 섹터/데드존 판정 → **deg/s 제어 법칙**
  (프레임당에서 초당으로 바꾼 이유 + FPS별 검증표) → 잠금 히스테리시스 → 쿨다운
  80ms 근거 → 소프트리밋
- **손실 복구 사다리** 전체: 3프레임 필터 → coast(15f/0.9) → hold 1s → BACK 2s → CENTER.
  관성 속도 = `카메라 각속도 + 화면 내 이동량 × 화각` 공식과 **두 성분이 모두 0일 때
  관성이 안 걸리는 안전 성질**, 감쇠가 거리를 지배한다는 측정표, 기각된 대안(등속 전환)
- 카운팅: `angle_3pt` 정의역 보호 + conf 게이트 → `RepCounter` 상태기계(히스테리시스 +
  dwell) → 종목별 임계·rep 정의 → **상체 2종이 각도 하나를 공유하는 이유**
- **알려진 실패 모드**를 숨기지 않고 적었다: `bottom=5°` 가짜 rep, 2D 투영 왜곡,
  rep 하나가 유효 샘플 2개로 성립하는 취약점, 기각한 대응 2건과 그 이유, 향후 후보
- 파일/함수 지도

### 4. `docs/web.md` (신규, **Fluid 한정**)

사용자 지시로 **현재 서빙 중인 Fluid 페이지만** 다룬다(React 시안 6종은 참조만).

- 가장 먼저: **`/app`은 React가 아니라 자체포함 정적 HTML 파일 하나**라는 사실
- 화면 구성 도식 + 자동/수동이 같은 자리를 공유하는 이유
- 라이브 판정과 데모 폴백(500ms 폴링, 3연속 실패 & 한 번도 성공 못 함 → getUserMedia)
- **stats.json → 화면 매핑 표**, 자세 피드백 우선순위(추적 상태가 운동 상태보다 우선)
- 제어권: `client_id="hcb-demo"` 공유 = **누구나 조종** 상태라는 것과 그 보안 의미
- 조작 경로(delta ±6/±8) + **낙관적 UI 1.5s/2.0s 창**이 왜 필요한지(폴링 되감기 방어)
- 스프링 엔진 config 값, 러버밴딩, 햅틱, `prefers-reduced-motion/transparency` 대응
- 820px 레이아웃 분기, `onLive` try/catch로 프리징 방어
- **배포 절차 + `npm run build`가 Fluid를 덮는다는 경고와 복원 명령**

### 5. `docs/HANDOFF.md` 상단에 주석 추가

07-17 문서라 §4·§5·§7의 푸시업 서술이 낡았다는 것과, 최신 맥락(`2026-07-26_05`) 및
새 상설 문서 3종의 위치를 앞에 명시. **§2·§3·§6·§8은 그대로 유효**임도 같이 적었다.

## 작성 방식

**문서를 문서로부터 쓰지 않고 코드에서 확인해 썼다.** `src/*.py` 전부(2,027줄),
`docker/{Dockerfile,run.sh,requirements.txt}`, `web/dist/index.html`(Fluid),
`web/src/{App.tsx,hooks,versions/registry.ts}`, `vite.config.ts`를 읽고 값을 대조했다.

대조 결과 **기존 문서의 수치는 코드와 일치했다** — 임계값(100/140, 60/140, 35/80),
PTZ 필드(0.62/0.20, 0.64/0.15, 15/0.9/60, 232/116), run.sh 자동탐색, Fluid 배포 상태 전부.

## 발견 — 코드에 남은 낡은 것 (문서에 기록, **미수정**)

1. **`docker/Dockerfile`의 `CMD`가 `--mode auto --serial /dev/ttyUSB0`** — `auto`는
   07-26에 argparse에서 제거됐다. 실사용 경로(`run.sh`)가 명령을 덮어쓰므로 지금은
   증상이 안 보이지만, **손으로 `docker run`하면 `invalid choice: 'auto'`로 즉시 종료된다.**
   07-26에 `run.sh`에서 고친 것과 **정확히 같은 함정이 Dockerfile에 하나 더 남아 있었다.**
2. **`st3215_bus.py::set_id` docstring**이 "실제 반영은 전원 재투입 후"라고 적고 있는데,
   실기에서는 즉시 반영되는 것으로 확인됐다(`issues/2026-07-16_01`). 코드 주석이
   이슈 문서와 반대다.
3. `pose_utils.py`·`exercise_counter.py`·`Dockerfile` 주석에 "squat + pushup"이라는 옛
   표현이 남아 있다(동작 무해).

> 셋 다 **문서 작업 범위를 넘는 코드 변경**이라 손대지 않고 `architecture.md` §13에
> 기록만 했다. 1번은 실제로 밟을 수 있는 함정이므로 다음 세션에서 고치는 것이 좋다.

## 검증

- 모든 상호 링크의 대상 파일 존재 확인.
- 문서에 적은 수치·플래그·API 경로를 코드와 1:1 대조(위 "작성 방식").
- markdownlint 경고(MD060 표 파이프 간격, MD040 코드펜스 언어)는 **기존 docs 전체가
  같은 스타일**이라 맞추지 않았다 — 문서 세트 내 일관성을 우선.

## 남은 것

- 위 "발견" 1번(Dockerfile CMD) 수정 여부 결정.
- `web/DESIGN.md`가 07-21 기준 "CALM 1종"으로 오래됨(실제 레지스트리 6종). `web.md`에
  각주로 표시만 해둠.
- `APP_GUIDE.md`도 React 시절 기준이라 `--mode auto`·푸시업·`/api/mode` 값이 낡았다.

## 관련

- 갱신: [`README.md`](../../README.md), HANDOFF.md (현 [`07_runbook.md`](../07_runbook.md))
- 신규: architecture.md · algorithms.md · web.md
  → **같은 날 번호 체계로 재편됨**: [`2026-07-30_02`](2026-07-30_02_docs_renumbered_into_parts.md)
  참고. 현재 위치는 [`01_architecture.md`](../01_architecture.md) ·
  [`03_algorithm_ptz_tracking.md`](../03_algorithm_ptz_tracking.md) ·
  [`05_web_ui_fluid.md`](../05_web_ui_fluid.md)
- 직전 맥락: [`2026-07-26_05`](2026-07-26_05_session_handoff.md)

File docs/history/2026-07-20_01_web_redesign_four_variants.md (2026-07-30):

# 2026-07-20 — 웹앱 전면 재설계: 디자인 시안 4종 + 폰트 self-host

## 시점

2026-07-20 새벽. CPU 사용률 텔레메트리
([`2026-07-19_03`](2026-07-19_03_cpu_usage_telemetry.md)) 이후, 웹 UI만
따로 떼어 야간 작업으로 진행했다.

## 사건

기존 웹앱을 백업하고 **완전히 다른 성격의 디자인 시안 4개**를 새로 만들었다.
같은 데이터(스쿼트 카운트 · MoveNet 자세 · UNO Q 상태 모니터링)를 네 가지
방식으로 해석한 것으로, 하나를 고르기 위한 비교용이다.

**추론 루프는 건드리지 않았다.** `src/*.py`(MoveNet, 카운터, PTZ 제어),
`/stats.json`·`/api/*` 계약 모두 그대로다. 순수 프론트엔드 작업.

## 백업

```
health_care_bot/backup/web_2026-07-20_pre_redesign/
```

`src/`·`public/`·`dist/`·설정 파일 전부. 되돌리려면 이걸로 덮고 재빌드.

## 시안 4종

| | 성격 | 바탕 | 강조 | 디스플레이 서체 |
|---|---|---|---|---|
| INSTRUMENT | 정밀 계측기 | `#0a0b0d` | 라임 `#c8f751` | Spline Sans Mono |
| ALMANAC | 기록하는 종이 | `#f4f0e6` | 벽돌 `#8a3b2c` | Newsreader |
| STADIUM | 중계 스코어보드 | `#0b0b0b` | 주황 `#ff3b00` | Archivo (wght+wdth) |
| CALM | 숨쉬는 코치 | `#eef2ef` | 딥그린 `#0f4c3a` | Gabarito |

전환: `/app?ui=<id>`, 화면 내 버튼, 키보드 `1`~`4`.
상세 설계 근거는 [`web/DESIGN.md`](../../web/DESIGN.md).

## 리서치 방법

Playwright로 22개 사이트(WHOOP·Oura·Strava·Linear·Vercel·Eight Sleep·
Nike·Arc·Withings·Peloton 등)를 열어 **계산된 스타일을 직접 긁었다** —
스크린샷 눈대중이 아니라 실제 렌더된 `font-family`, 면적 가중 배경색,
텍스트 색, `border-radius`, `font-weight` 분포를 뽑았다.

여기서 나온 구체적 수치가 팔레트 결정의 근거가 됐다. 예: Linear는
`#08090a` 바탕에 2~6px radius, Oura는 `#f7f1e8` 크림 + 고대비 세리프,
Strava는 `#fc5200` 단일 강조색에 radius 4px.

## 뒤집힌 초기 판단

리서치가 처음 고른 서체 대부분을 무효화했다.

1. **Instrument Serif → Newsreader.** Instrument Serif는 Space Grotesk·
   Geist와 묶여 2026년 기준 "AI가 만든 화면"의 표식으로 지목되는 조합이다.
   Newsreader는 숫자가 기본 tabular + lining이라 표에 그대로 쓸 수 있다.
2. **Fraunces 탈락.** 바이너리를 뜯어보니 **`tnum` 기능이 아예 없다.**
   실시간으로 바뀌는 숫자를 다루는 앱에서 자릿수가 흔들리는 서체는
   후보가 될 수 없다.
3. **Anton → Archivo.** Anton은 단일 굵기. Archivo는 wght+wdth 2축이라
   압축 디스플레이(`wdth 78`)를 파일 하나로 내고 숫자 기능이 충실하다.
4. **Outfit → Gabarito**, **JetBrains Mono → Spline Sans Mono.**
   앞의 둘은 기본값 인상이 강해서 교체.

## 실제로 고친 결함

- **INSTRUMENT 팔레트 대비 미달.** `--ink-3`가 라벨 텍스트로 18곳에
  쓰이는데 읽기 한계 아래였다. 더 나쁜 건 **`--crit`(위험)이
  `--warn`(주의)보다 어두워서 가장 급한 상태가 가장 안 읽혔다는 점.**
  둘 다 밝은 쪽으로 올렸다.
- **`word-break: keep-all` 누락.** 한글 음절은 유니코드상 표의문자로
  분류돼서, 기본값이면 브라우저가 아무 음절 사이에서나 줄을 끊는다
  ("한국어를" → "한국 / 어를"). 한국어는 어절 사이를 띄우므로 이건
  틀린 동작이다. 전역 적용.
- **`font-feature-settings` 우선순위 함정.** 이게
  `font-variant-numeric`보다 우선해서, 어딘가에서 한 줄 선언되면
  tabular이 조용히 무력화된다. 숫자 요소에 방어적으로 `normal`을 건다.
- **커닝이 tabular을 깨는 경우.** 일부 서체는 고정폭 숫자에까지 커닝
  페어를 걸어둬 `"11111"`과 `"00000"` 폭이 달라진다. `font-kerning: none`.
- **`ch` 단위 함정.** Pretendard는 `1ch`가 tabular 자폭보다 약 3% 좁아서
  `width: 5ch`로 숫자 칸을 잡으면 조용히 잘린다. 안 썼다.

## 폰트 self-host — 2.0MB → 226KB

로봇은 LAN 전용이라 **구글 폰트 CDN에 못 나간다.** CDN을 쓰면 시연장에서
폰트만 통째로 안 뜨는 사고가 난다. 전부 self-host로 갔다.

문제는 Pretendard 원본이 2.0MB라는 것(한글 음절 11,172자 전부).
"QR 스캔 후 3초" 목표와 정면으로 부딪힌다.

`scripts/subset_pretendard.py`로 unicode-range 조각을 만든다.

**첫 시도(코드포인트 순 44조각)는 실패했다.** 한 화면에 쓰이는 글자가
조각 전체에 흩어져 있어서 텍스트 많은 시안이 **37조각을 요청**했다.
쪼갠 의미가 없었다.

**두 번째 시도가 통했다.** 소스에 실제로 등장하는 글자만 모은
`kr-core.woff2`(105KB)를 만들어 **맨 앞에 선언**하고, 나머지는 안전망으로
뒤에 뒀다. 안전망 조각은 문구를 바꿨을 때만 쓰이고, 모든 글자가 어딘가에는
있으므로 **두부(□)가 원천적으로 불가능하다.**

결과 (실측):

| 시안 | 폰트 전송량 | woff2 요청 수 |
|---|---|---|
| INSTRUMENT | 262 KB | 3 |
| ALMANAC | 346 KB | 4 |
| STADIUM | 314 KB | 3 |
| CALM | 260 KB | 3 |

Pretendard 원본 단독 2,009 KB → **공통 226 KB (base 121 + kr-core 105)**.
37요청 → 3~4요청.

원본은 `web/fonts-src/`에 둔다. `public/`에 두면 dist에 2MB가 그대로 실린다.

## 데모 모드

로봇 없이 시안을 검토·발표 리허설할 수 있게 `?demo=1`을 넣었다.
`/stats.json`에 한 번도 못 붙으면 자동으로 켜진다 — **실제 stats가
한 번이라도 도착하면 켜지지 않으므로 디바이스 동작에는 영향이 없다.**

합성 데이터는 실측 범위에 맞췄다(FPS 10.8, CPU 83%, 스쿼트 주기 3.2초).
카메라 자리에는 MoveNet과 같은 17 keypoint 골격을 무릎 각도에 맞춰 그린다.
데모일 때는 화면에 항상 표식이 뜬다(`DEMO`/`견본`/`둘러보기`).

## 구조

시안끼리 **스타일을 공유하지 않는다.** 각 시안이 자기 `.tsx` + `.css`를
통째로 소유하고 lazy로 나뉘어 있어, 보고 있는 시안의 CSS만 로딩된다.
네 벌의 CSS가 한꺼번에 들어와 서로 덮어쓰는 사고를 구조적으로 막았다.

공유하는 건 데이터와 동작뿐 — 훅은 값을 계산하고 상태를 관리할 뿐
마크업을 만들지 않는다(`useStats`, `useMjpeg`, `useRepPulse`,
`useSeries`, `usePressRepeat`, `useVersion`).

## 검증

`npm run build` 통과 + Playwright로 4시안 × 모바일(402px)/데스크톱(1440px):

- 각 시안이 자기 디스플레이 서체를 실제로 로드하는지 (폴백 아님) ✓
- Archivo `wdth: 78` 축이 실제로 적용되는지 ✓
- 큰 숫자에 tabular-nums가 걸려 있는지 ✓
- 가로 스크롤 없음 ✓
- 시안 전환 시트 열림 ✓
- 콘솔 에러 없음 ✓

## 남은 것

- **실기 미검증.** 데모 데이터와 빌드까지만 확인했다. UNO Q에 올려
  실제 MJPEG 스트림·실제 PTZ 조작으로 보는 건 아직 안 했다.
- 실제 스트림이 들어왔을 때의 프레임 밀도, 조작 지연, 발열 영향 확인 필요.
- 아이폰 사파리 실기 확인.
- 시안 4개 중 하나를 고르고 나머지를 정리하는 작업.

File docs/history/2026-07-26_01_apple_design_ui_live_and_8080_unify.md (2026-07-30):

# 2026-07-26 — 애플 디자인 라이브 UI 신규 + 8080 통일 + 모바일 접속 디버그

## 시점

2026-07-26. Emil Kowalski의 Apple 디자인 스킬을 설치한 뒤, 기존 웹앱과 별개로
라이브 화면 시안을 새로 만들고 로봇 실카메라에 연동, 최종적으로 `:8080/app`으로
통일했다.

## 한 일

### 1. Apple 디자인 스킬 설치

`npx skills@latest add emilkowalski/skills`로 전역(`~/.claude/skills`) 설치:
`apple-design`, `emil-design-eng`, `review-animations`, `improve-animations`,
`animation-vocabulary` (+ 저장소엔 `find-animation-opportunities`,
`pick-ui-library`도 있음). `review-animations`는 `disable-model-invocation:true`라
사용자가 `/review-animations`로 **직접 호출할 때만** 동작. (`frontend-design`은
플러그인 마켓플레이스에 있으나 이 CLI 세션엔 미로드 — SKILL.md 내용으로 적용.)

### 2. 라이브 화면 시안 2종 신규 (`design_demos/`)

- **`live_frontend-design.html` — "Field Optics"**: 로봇의 *시선/PTZ 추적*을 정체성으로,
  광학 계기(레티클·FOV·mono 텔레메트리) 컨셉. 카메라 피드 듀오톤 처리(리스크).
  팔레트: 웜 본 + 딥 스프루스 + 형광 샤르트뢰즈 (Toss 보라/파랑 기본값·AI 클리셰 회피).
- **`live_apple-design.html` — "Fluid"**: apple-design 스킬 원칙 구현 — 직접 만든
  스프링 엔진(감쇠/response), 액티비티 링, 러버밴딩·속도 핸드오프·관성 투영,
  reduced-motion. **이후 이게 메인이 됨.**

### 3. 로봇 실카메라 연동

두 페이지 모두 `location.hostname:8080`의 `/stats.json`을 폴링해 잡히면 **라이브 모드**:
히어로=`/stream.mjpg`(스켈레톤 baked-in), 레티클=실제 `person_center_norm`,
링/모드/PTZ/피드백=실제 stats. 없으면 `getUserMedia` 데모 폴백. `stats.json`은
`Access-Control-Allow-Origin:*`라 크로스오리진 OK.

### 4. SSH 배포 + 공유 제어권

- 파일을 디바이스 `~/health_care_bot/design_demos/`로 전송, `python -m http.server 8777`
  (0.0.0.0) 서빙.
- **공유 제어권**: 모든 클라이언트가 같은 `client_id="hcb-demo"` + PIN `1234`로
  제어권을 공유 → **누구나 조종**(마지막 명령 우선, 격리 없음). 조이스틱이 실제
  `/api/ptz`로 서보 구동, 운동모드/auto_track도 실제 API.

### 5. Fluid 반복 개선 (최종 형태)

- 운동 세그먼트 **Auto 제거 → Squat / Push-up(비활성)**.
- PTZ 카드 **자동추적 ⇄ 직접조작** 토글: 자동=**텔레메트리**(FPS·추론 loop ms·CPU 온도·RAM·CPU%),
  수동=**조이스틱**(실서보). 실제 `ptz.auto_track_enabled` 반영.
- 상단 **설정 기어(⚙) → QR 모달**로 모바일 접속(자체 인라인 QR SVG, segno 생성).
- **컴퓨터/모바일 분리 레이아웃**: 폰 = 100dvh 한 화면(카메라 flex 축소), 컴퓨터(≥820px)
  = 단일 세로 컬럼 **큰 카메라 위 + 정보 패널 아래**(카메라 안 줄임, 스크롤).
- `onLive` 전체 try/catch + 방어적 필드 접근(한 프레임 이상해도 프리징 방지).

### 6. 8080 통일 + run.sh에 카메라 굽기 (영구화)

- **`web/dist/index.html` = 애플 페이지**로 교체 → `/app`이 애플 디자인. 기존 stock은
  `web/dist/index.html.stock.bak` 백업. 로컬 레포도 동일하게 맞춤. QR도 `:8080/app`으로 재생성.
  이제 **:8777 불필요, 포트 하나(8080)로 통일.**
- **`docker/run.sh`에 USB 카메라 자동탐색 추가**: `/sys/class/video4linux/*/name`에서
  이름에 `Camera` 있는 노드 선택(Venus 코덱 회피), 기본 `/dev/video2`. → **`bash docker/run.sh`
  만으로 카메라 2번** 자동 사용(부팅마다 노드 바뀌어도 자동).

### 7. 모바일 접속 디버그

폰 접속 실패를 추적 → **폰 랜덤 MAC**이 원인으로 판명(별도 이슈
[`2026-07-26_01`](../issues/2026-07-26_01_mobile_web_access_fails_random_mac.md)).

## 검증

- `bash docker/run.sh`(env 없이) → 로그 `camera : /dev/video2 640x480`, `actual : 640x480`(정상 오픈).
- `/app is apple: True`, `stats.json` 라이브 fps ~10, `ptz in_frame`. PC 접속 HTTP 200.
- 두 시안 JS `node --check` 통과.

## 주의 / 되돌리기

- **애플 페이지는 자체 포함 정적 HTML** → React `npm run build` 대상 아님. 빌드하면
  `web/dist/index.html`이 stock 앱으로 덮이므로, 그때 애플로 되돌리려면
  `design_demos/live_apple-design.html`(또는 QR을 :8080/app로 맞춘 빌드본)을 다시 배포.
  stock 복원: `web/dist/index.html.stock.bak`.
- 07-20 웹 백업(`backup/web_2026-07-20_pre_redesign/`)으로 롤백을 시도했었으나, 접속 실패
  원인이 프론트가 아니라 폰이었으므로 롤백은 원복했다(web/dist는 다시 최신/애플).

## 관련

- 시안 원본: `design_demos/live_apple-design.html`, `live_frontend-design.html`
- 이슈: [`issues/2026-07-26_01_mobile_web_access_fails_random_mac.md`](../issues/2026-07-26_01_mobile_web_access_fails_random_mac.md)
- 실행: `cd ~/health_care_bot && bash docker/run.sh` → `http://192.168.0.45:8080/app`

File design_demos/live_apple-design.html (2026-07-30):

# Health Care Bot

연결 중

CAM · 자동 추적

0/ 20

현재 운동

—

로봇에 연결하는 중…

📷카메라 켜기

스쿼트 숄더프레스 레터럴

## 카메라 · PTZ

—

자동 추적 직접 조작

—FPS

—추론 ms

—CPU °C

—RAM MB

CPU —%

PAN0.0°TILT0.0°

기울인 방향으로 카메라가 움직입니다 · 놓으면 정지

### 모바일 접속

폰 카메라로 QR을 스캔하면 이 화면이 열립니다.

—복사

닫기

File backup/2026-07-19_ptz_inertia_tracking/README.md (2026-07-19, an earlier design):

# 2026-07-19 — PTZ 관성 추적 시점 스냅샷

`src/ptz_controller.py` 백업. git 커밋 `9eeee60` (태그 `v3`)과 동일한 내용.

## 이 시점에 담긴 것

- **시간 기준 제어** — 추적 속도가 deg/s로 표현돼 프레임레이트와 무관
  (`gain_deg_per_s=232`, `max_deg_per_s=116`)
- **명령 쿨다운 80ms** — 서보(50 deg/s)가 목표보다 빨라 먼저 도착해 멈추던
  문제 해소 (기존 250ms)
- **추적 손실 관성 복구 사다리** (yaw 전용)
  관성 -> 1초 대기 -> 관성 이전 복귀 -> 2초 대기 -> 중앙 복귀.
  어느 단계든 재검출되면 즉시 취소.
- **관성 속도 = 카메라 각속도 + 화면 내 피사체 이동량 x 화각**
  둘 중 하나만 보면 놓치는 경우가 있어 합으로 낸다. 상세는
  `docs/history/2026-07-19_02`.

## 튜닝값

| 필드 | 값 |
|---|---|
| `coast_start_misses` | 3 |
| `coast_frames` | 15 (11 FPS에서 1.36초) |
| `coast_decay` | 0.9 (약 44도 이동) |
| `coast_fov_deg` | 60 (**추정값 — 실측 보정 필요**) |

## 실기 확인 결과 (2026-07-19, 스냅샷 이후 추가 기록)

**이 튜닝값 그대로 로봇에서 동작 확인 완료 — 잘 따라간다.** 최초 문제였던
"빠르게 나가면 못 따라온다"도 해소 확인됨. 스냅샷 당시에는 시뮬레이션 검증만
통과한 상태였으나, 이후 실기에서 검증되어 조정 없이 유지됐다.

`coast_fov_deg=60`은 여전히 실측이 아닌 추정값이지만 실사용에 문제가 없어
정밀 보정은 필요해지는 시점으로 미룬다.

## 되돌리기

```powershell
Copy-Item backup\2026-07-19_ptz_inertia_tracking\ptz_controller.py src\ptz_controller.py
```

git이 있으므로 아래도 동일하다:

```powershell
git checkout v3 -- src/ptz_controller.py
```

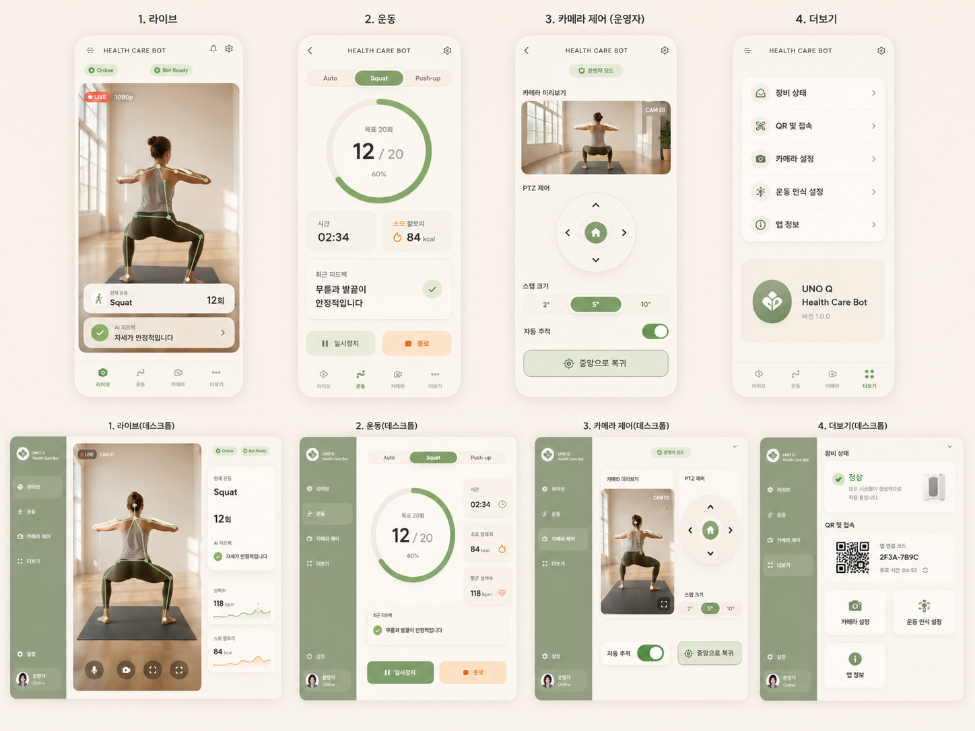
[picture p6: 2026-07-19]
app_reference.png

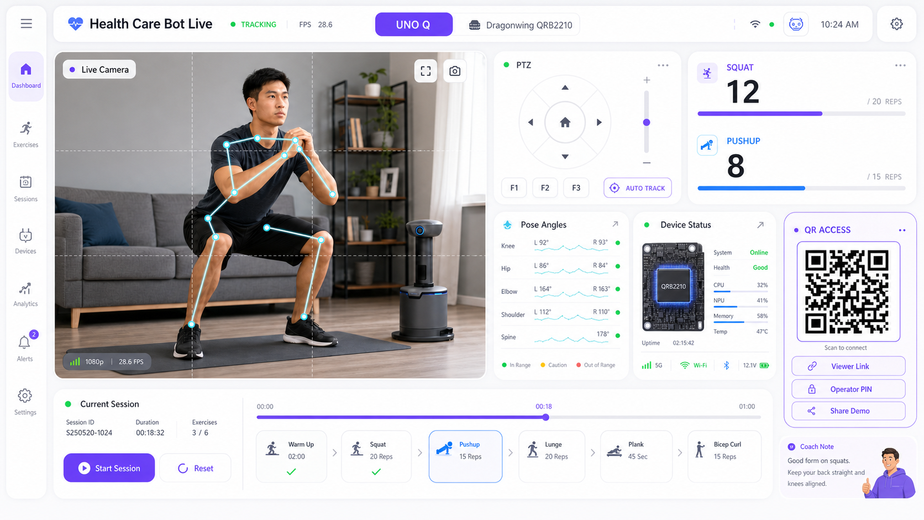
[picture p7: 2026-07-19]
docs/assets/health-care-bot-app-reference.png

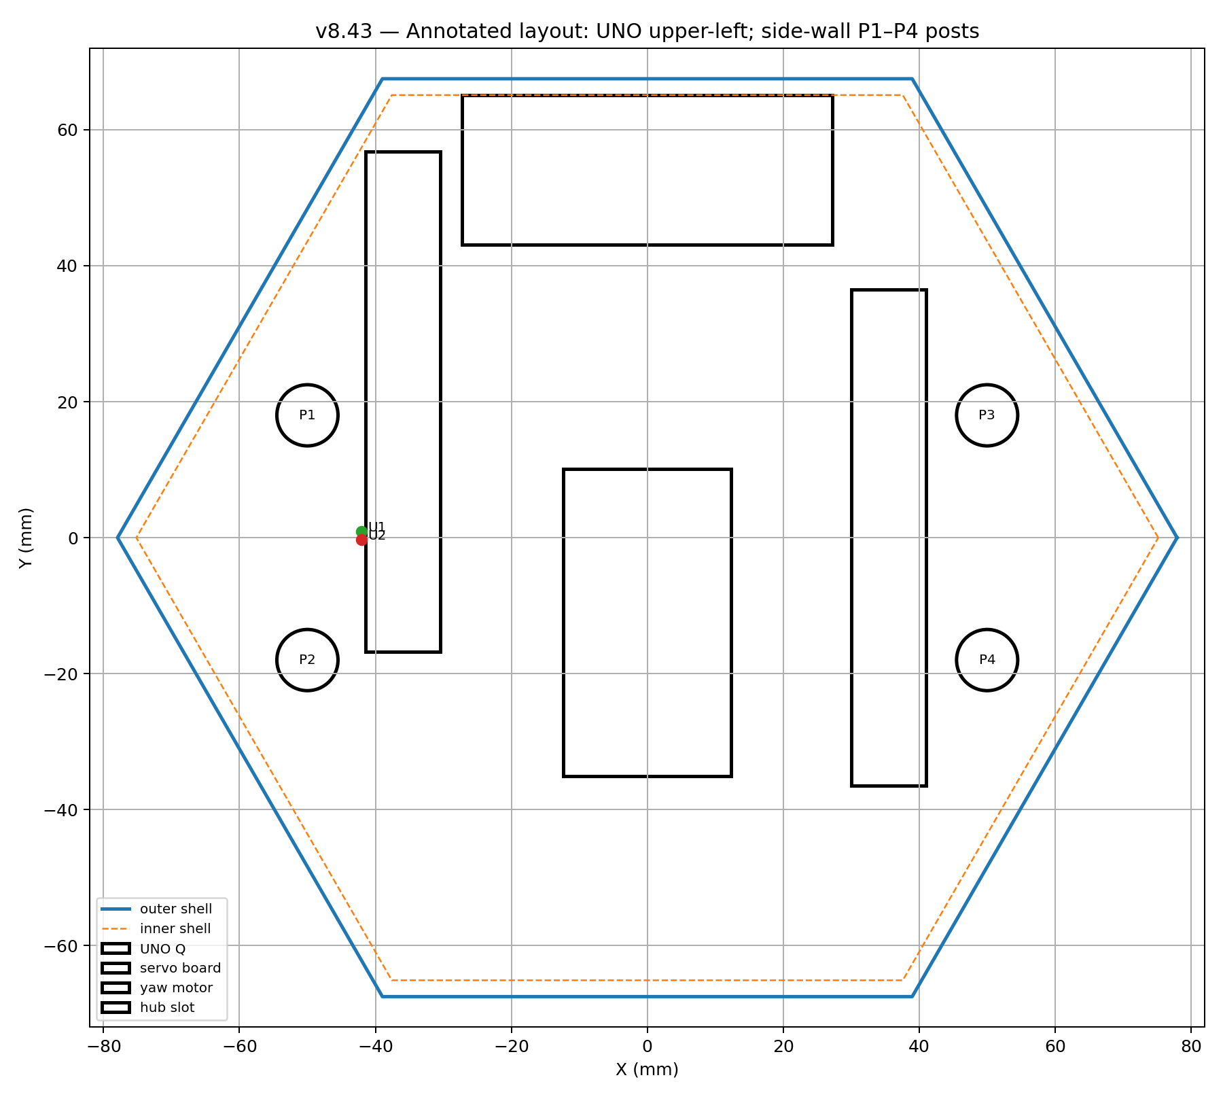
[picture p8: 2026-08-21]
3d_model/preview/v8_43_top_layout.png

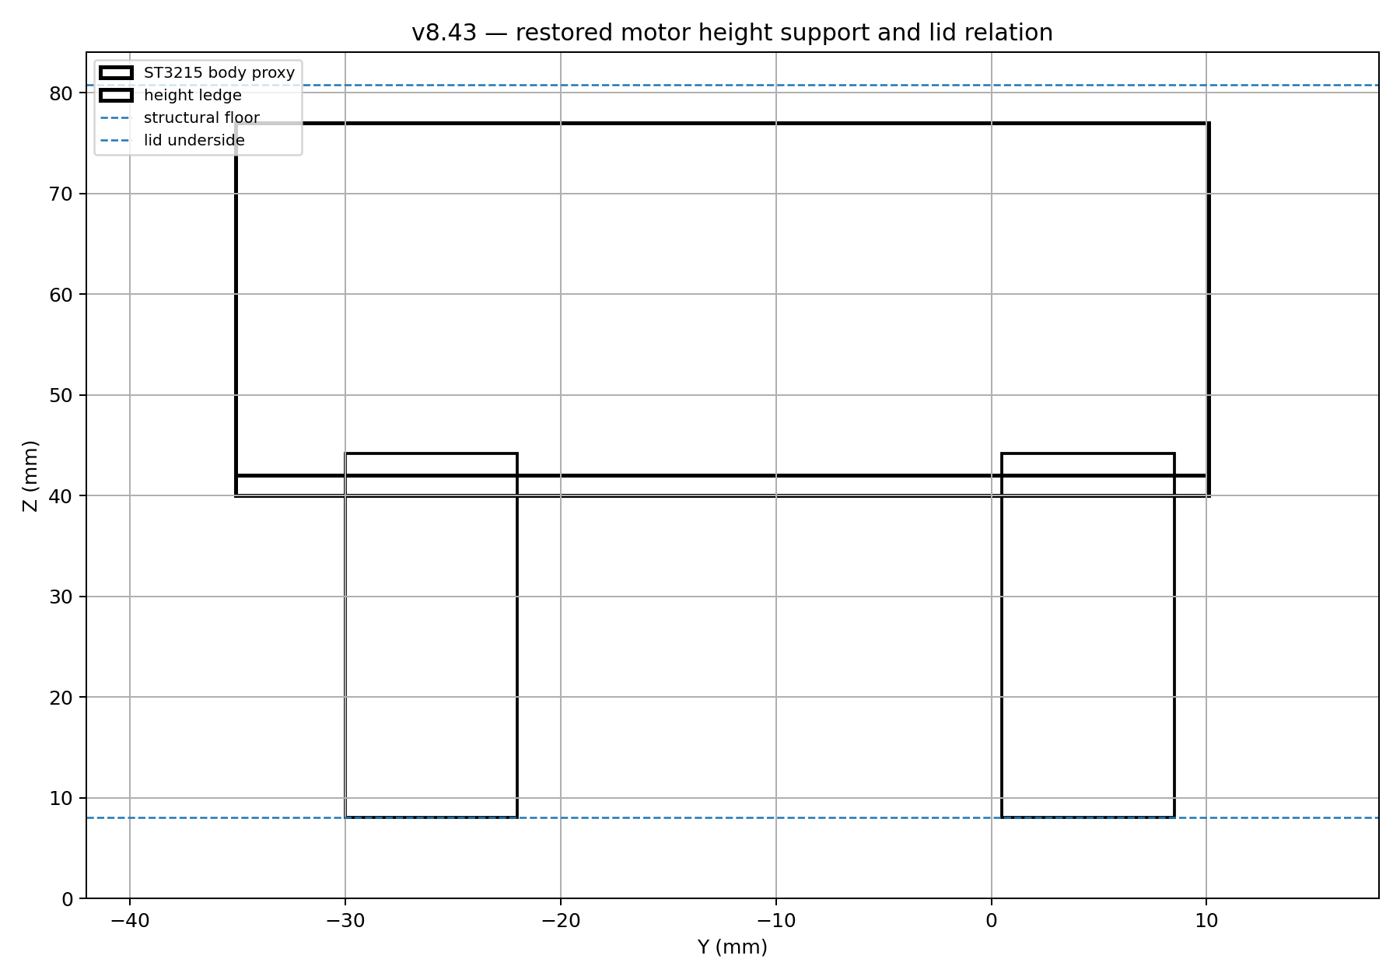
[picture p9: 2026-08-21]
3d_model/preview/v8_43_motor_height_support.png

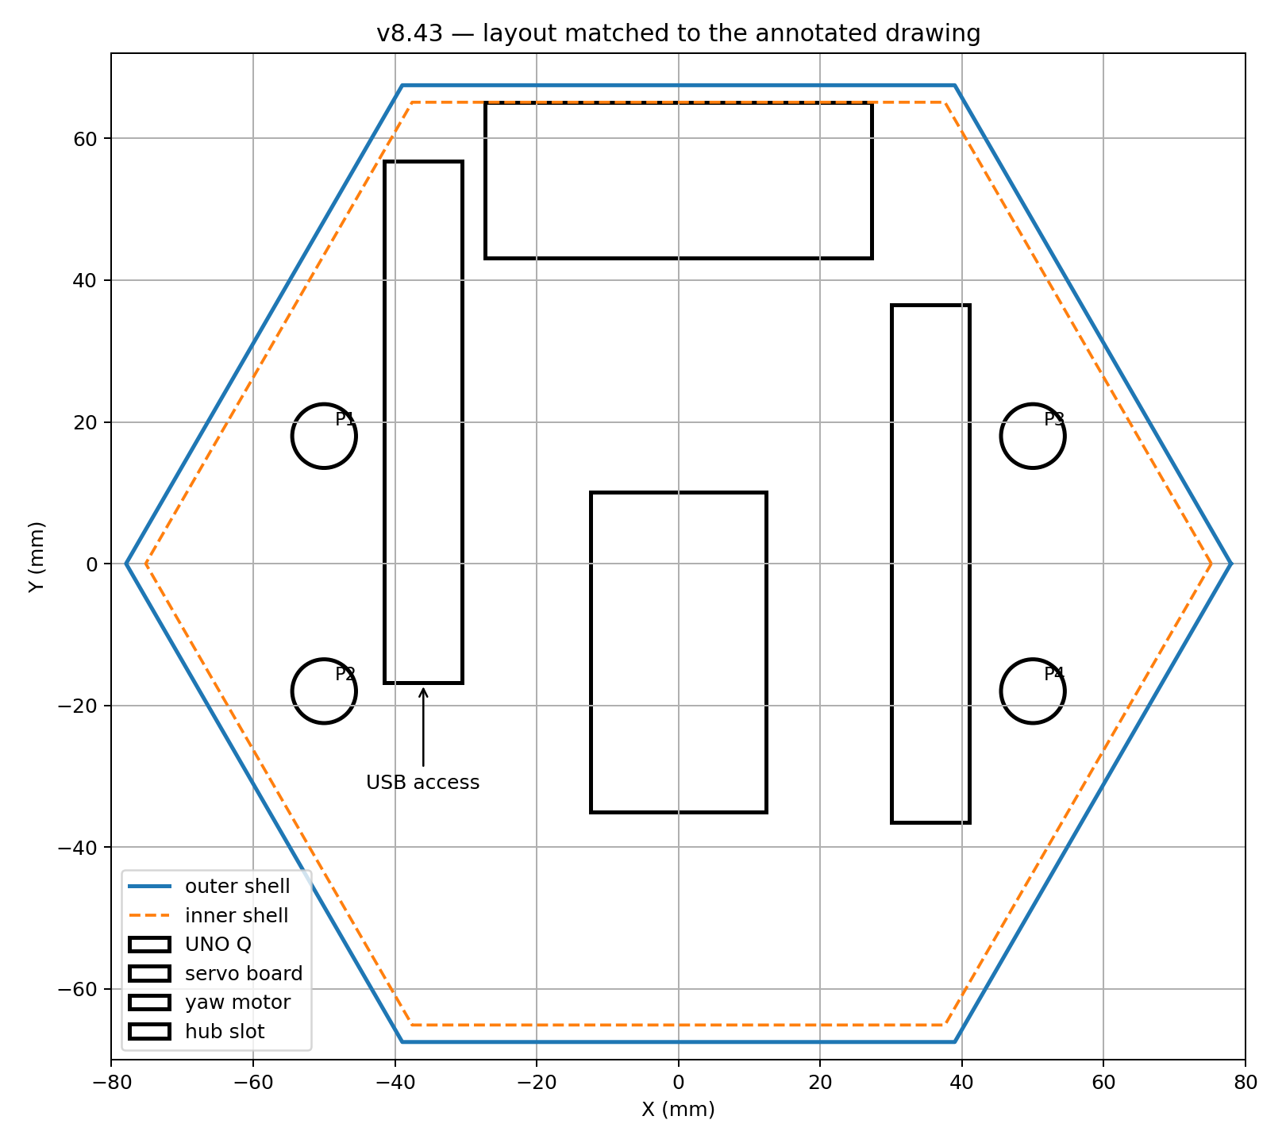
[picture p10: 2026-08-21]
3d_model/preview/v8_43_annotated_layout.png

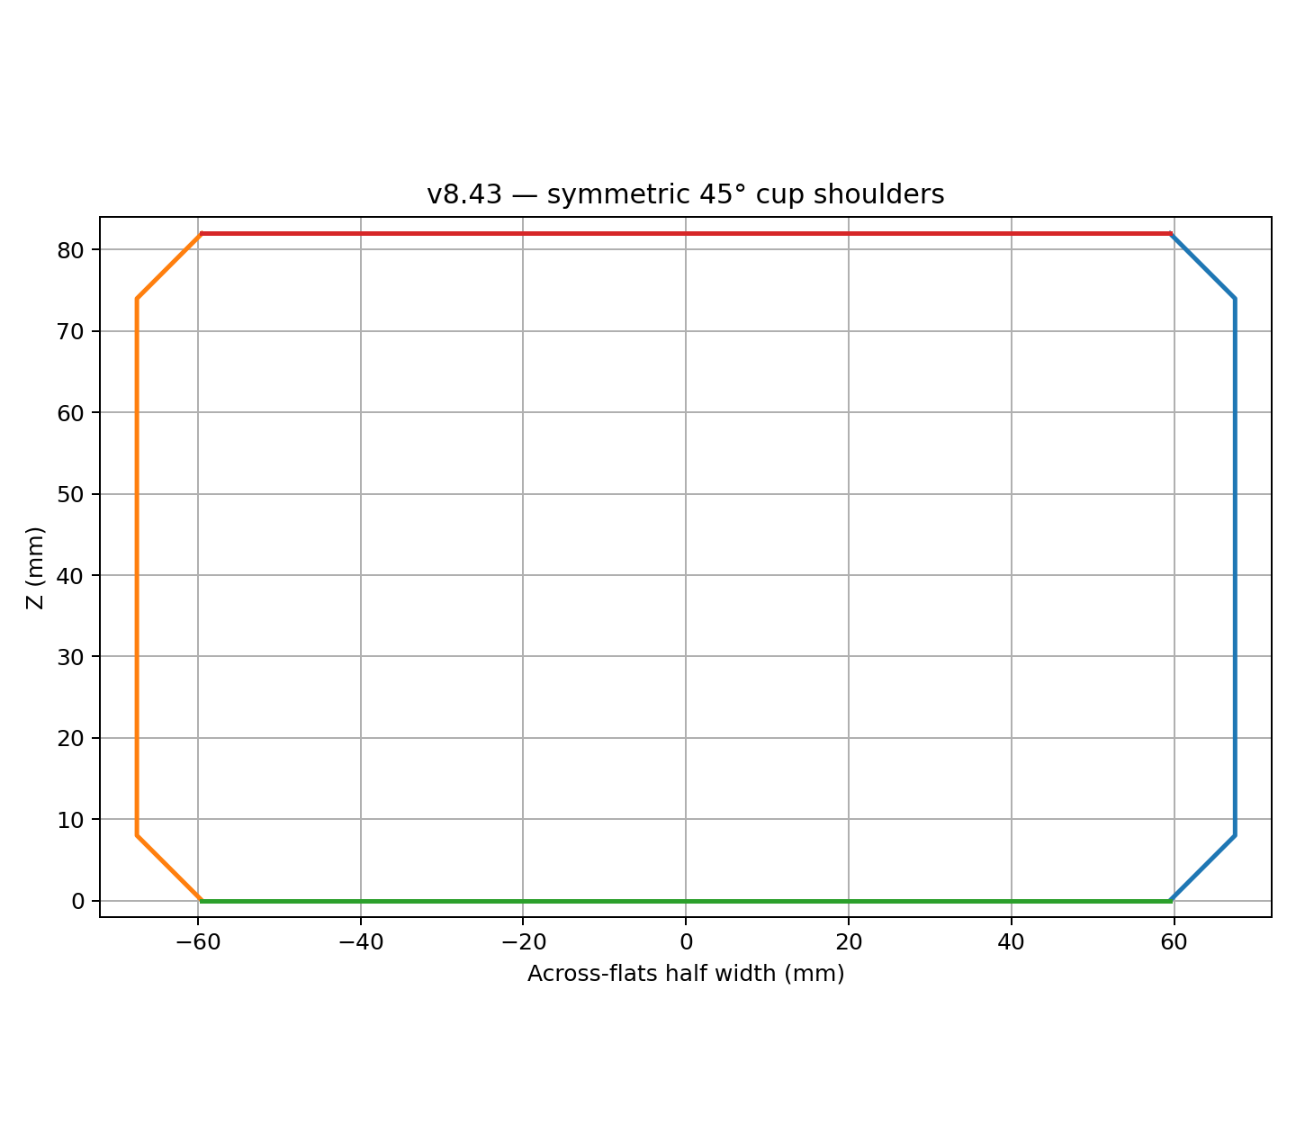
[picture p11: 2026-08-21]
3d_model/preview/v8_43_45deg_profile.png

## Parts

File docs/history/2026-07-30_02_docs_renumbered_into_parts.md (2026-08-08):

# 2026-07-30 — docs를 번호 체계(00~09)로 재편, 파트별 분할

## 시점

2026-07-30. 같은 날 [`2026-07-30_01`](2026-07-30_01_docs_readme_architecture_algorithms_web.md)에서
README를 최신화하고 상설 문서 3종(architecture/algorithms/web)을 만든 직후. 사용자 요청으로
**pose 라인(`unoq-pose/docs`)의 번호 체계 스타일**에 맞춰 docs 전체를 재편했다.

## 왜

세 가지 문제가 겹쳐 있었다.

1. **진입 순서가 없었다.** 파일명이 `HANDOFF.md`, `exercise_detection.md`,
   `reassembly_checklist.md`처럼 평면적이라 "무엇부터 읽어야 하는가"가 파일 목록에서 드러나지
   않았다. 번호가 붙으면 순서 자체가 정보가 된다.
2. **한 문서가 여러 주제를 안고 있었다.** `HANDOFF.md`는 하드웨어 값 + 실행법 + 함정표 +
   PTZ 튜닝 + 다음 할 일을 한꺼번에 담아 어느 절이 유효한지 매번 판단해야 했고, 실제로 07-26
   종목 개편 이후 §4·§5·§7이 stale해진 상태였다. `algorithms.md`도 PTZ와 운동 카운팅이라는
   별개 주제 두 개를 담고 있었다.
3. **중복.** `exercise_detection.md`(종목 설계)와 `algorithms.md` §2(카운팅 수식)가 같은 내용을
   다르게 서술하고 있었다.

pose 라인이 이미 `00_project_blueprint.md` ~ `09_*.md` + `history/` + `issues/` 구조를 쓰고
있었으므로, 같은 스타일로 맞추면 두 라인을 오갈 때 인지 비용도 줄어든다.

## 무엇을

### 1. 최종 구조 (docs/)

| # | 파일 | 담는 것 |
|---|---|---|
| 00 | `00_project_blueprint.md` | 청사진 — 목적·실측 현황·검증 상태·디렉토리·문서 지도·문서 규칙 |
| 01 | `01_architecture.md` | 프로세스/스레드, 파이프라인, 모듈 경계, 상태 소유권, 서보 경로, degrade |
| 02 | `02_http_api_and_stats.md` | HTTP 엔드포인트 계약, 제어권 모델, `stats.json` 전체 스키마, 필드 함정 |
| 03 | `03_algorithm_ptz_tracking.md` | PTZ 제어 법칙, 존 판정, 잠금, 손실 복구 사다리, 튜닝, 한계 |
| 04 | `04_algorithm_exercise.md` | 각도 정의, RepCounter 상태기계, 종목별 임계, 실패 모드, 푸시업 제외 근거 |
| 05 | `05_web_ui_fluid.md` | Fluid 화면·라이브 판정·제어권·조작·모션·배포 |
| 06 | `06_hardware_calibration.md` | 하드웨어 확정값, EEPROM 사고 이력, 재조립 5단계 절차, 벤치 도구 |
| 07 | `07_runbook.md` | 디바이스/PC 실행, 노드 확인, 배포(SSH/adb), 목업 개발, 종료 체크리스트 |
| 08 | `08_troubleshooting.md` | 증상 → 원인 색인 7개 분류 + `issues/` 전체 목록 |
| 09 | `09_performance_roadmap.md` | 성능 실측·병목 근거, 개선 레버, 다음 할 일 우선순위, 기각 목록 |

`history/`·`issues/`는 그대로 유지했다.

### 2. 파일 이동 매핑 (old → new)

| 이전 | 이후 | 방법 |
|---|---|---|
| `HANDOFF.md` | **분해** → `06`(§3 하드웨어) · `07`(§2 실행/환경) · `08`(§6 함정표) · `03`(§8 PTZ 튜닝) · `09`(다음 할 일) | `git mv` → `07_runbook.md` 후 재작성 |
| `exercise_detection.md` | `04_algorithm_exercise.md` (+ `algorithms.md` §2 카운팅 수식 병합) | `git mv` |
| `reassembly_checklist.md` | `06_hardware_calibration.md` (+ HANDOFF §3 하드웨어 값 병합) | `git mv` |
| `architecture.md` | `01_architecture.md` (+ API·스키마는 `02`로, 성능은 `09`로, 배포는 `07`로 분리) | rename |
| `algorithms.md` | `03_algorithm_ptz_tracking.md` (PTZ만) + `04`(운동) | rename + 분할 |
| `web.md` | `05_web_ui_fluid.md` | rename |
| (없음) | `00_project_blueprint.md` · `02_http_api_and_stats.md` · `08_troubleshooting.md` · `09_performance_roadmap.md` | 신규 |

**스텁을 남기지 않았다**(사용자 결정). 대신 아래 링크를 전부 갱신했다.

### 3. 스타일 통일 (pose 라인 규약)

- 파일명 `NN_snake_case_topic.md`
- 제목 다음에 **"본 문서는 … 정리합니다"** 목적 문단 — 대상 독자와 범위를 한 문단으로
- 절 번호는 **`## 0.` (한 눈에/요약)** 부터 시작, 하위는 **`### N-1.`** (점이 아니라 하이픈)
- 표 중심 서술, 상호 참조는 문서 번호로 (`[03](03_...md) §9`)

### 4. 링크 갱신

- `README.md` — 문서 지도를 00~09 표로 교체, 본문 참조 8곳 재지정
- `history/2026-07-26_04` · `2026-07-26_05` — `exercise_detection.md` 링크 → `04_...`
- `history/2026-07-26_05` — 옛 경로를 가리키는 안내 블록 추가(HANDOFF가 06/07/08로 분해됐음)
- `history/2026-07-30_01` — 본 재편으로 문서 위치가 바뀌었음을 명시 + 본 문서로 연결

## 원칙 — history는 고치지 않는다 (예외: 링크 경로)

`history/`·`issues/`는 그 시점의 기록이므로 **주장·수치·서술을 바꾸지 않았다.** 이번에 손댄
것은 **파일 이동으로 깨진 링크 경로**와, 옛 경로를 찾는 사람을 위한 **안내 블록 추가**뿐이다.
이 규칙 자체를 `00_project_blueprint.md` §7에 명문화했다.

## 검증

- **깨진 상대 링크 0건** — 새 문서 10개 + README + 수정한 history 3개의 모든 마크다운 링크를
  스크립트로 검사(존재 여부 확인).
- 코드(`src/`, `scripts/`, `docker/`)가 참조하는 docs 경로는 `history/`·`issues/`뿐이고, 이 두
  폴더는 움직이지 않았으므로 **코드 주석 링크는 영향 없음**을 grep으로 확인.
- 추적 파일 3개는 `git mv`로 옮겨 **rename으로 인식**된다(이력 보존).

## 남은 것

- `web/DESIGN.md`(07-21 기준, "CALM 1종"으로 서술 — 실제 6종)와 `APP_GUIDE.md`(React 시절,
  `--mode auto`·푸시업 언급)는 이번 재편 대상이 아니었다. `docs/00` §6-3에 "낡음"으로 표시만 해둠.
- `docker/Dockerfile`의 `CMD`가 아직 `--mode auto`다(손으로 `docker run`하면 즉시 종료).
  문서에는 기록했고(`01` §7-1, `08` §1) **코드는 미수정**.

## 관련

- 직전: [`2026-07-30_01`](2026-07-30_01_docs_readme_architecture_algorithms_web.md) — README 최신화 + 문서 3종 신설
- 참조 스타일: pose 라인 `unoq-pose/docs/00~09`
- 결과 진입점: [`00_project_blueprint.md`](../00_project_blueprint.md)

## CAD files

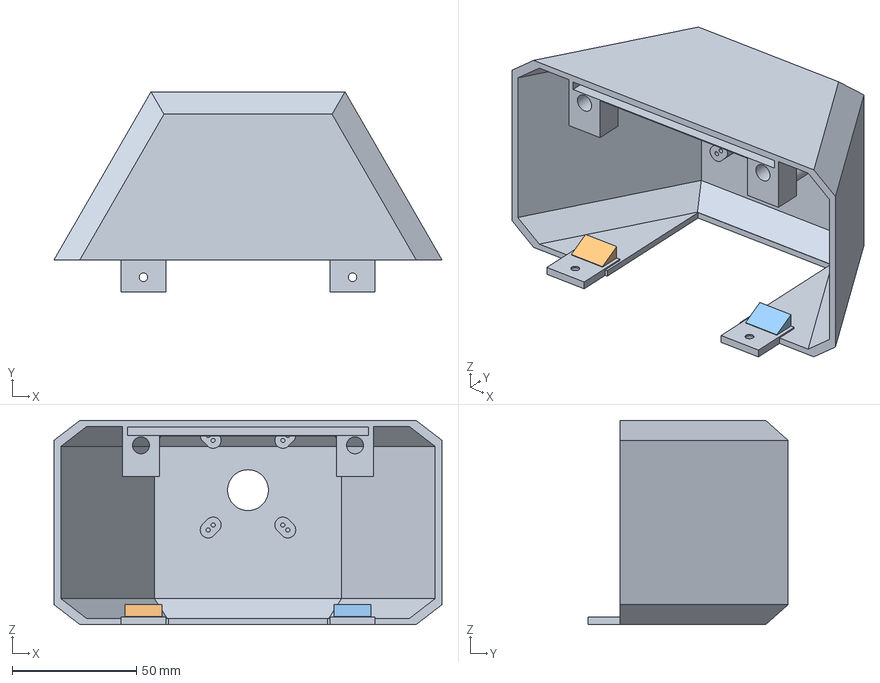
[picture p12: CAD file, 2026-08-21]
3d_model/3mf/head_front_reinforced_components.3mf
155.9 x 80.5 x 82.0 mm
head_front_original
front_tongue_reinforcement_1
front_tongue_reinforcement_2

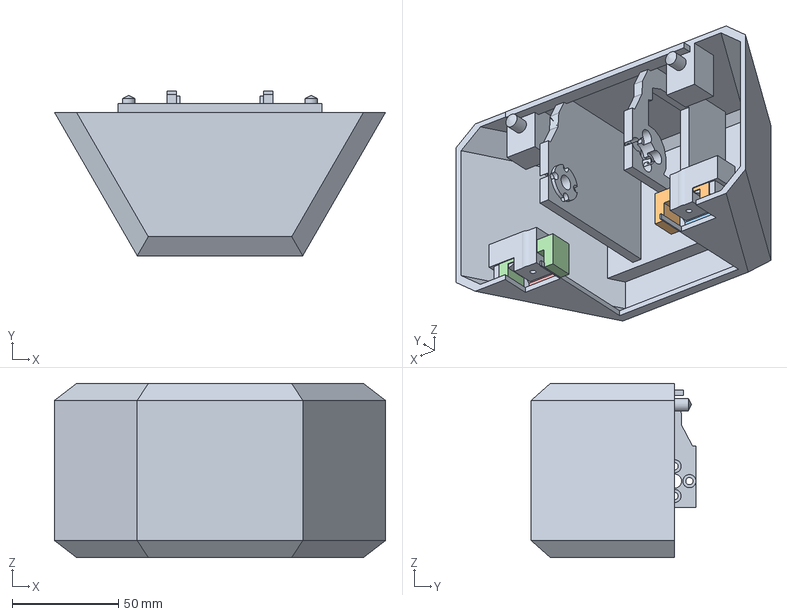
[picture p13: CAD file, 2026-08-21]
3d_model/3mf/head_back_reinforced_components.3mf
155.9 x 77.5 x 82.0 mm
head_back_original
back_floor_reinforcement_1
back_floor_reinforcement_2
back_floor_reinforcement_3
back_floor_reinforcement_4

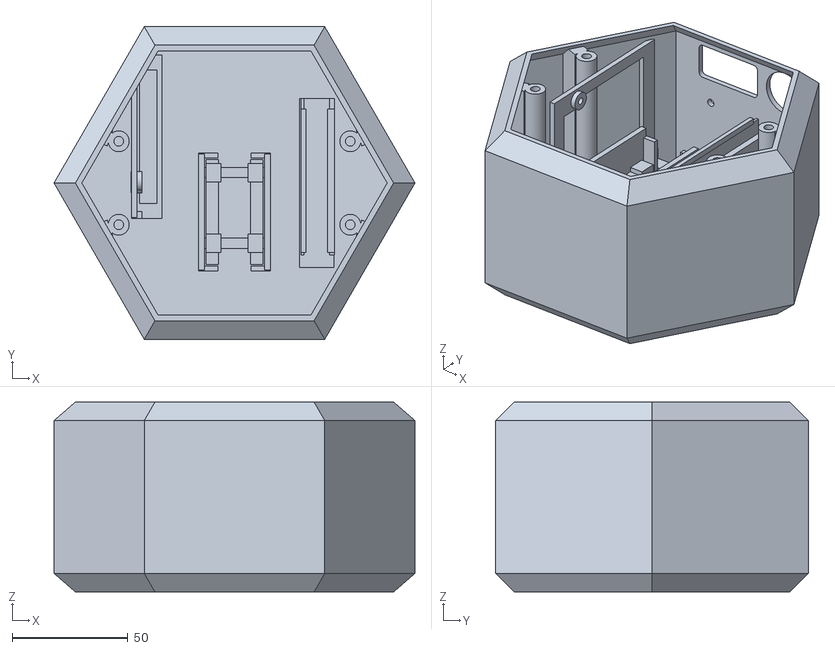
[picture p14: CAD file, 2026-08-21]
3d_model/stl/cup.stl
155.9 x 135.0 x 82.0

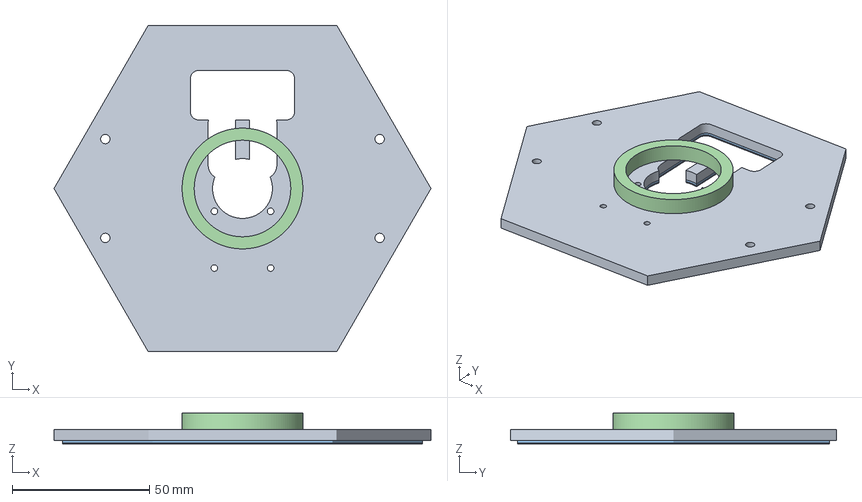
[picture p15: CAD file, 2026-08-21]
3d_model/3mf/lid_components.3mf
137.4 x 119.0 x 11.2 mm
lid_000
lid_001
lid_002
lid_003

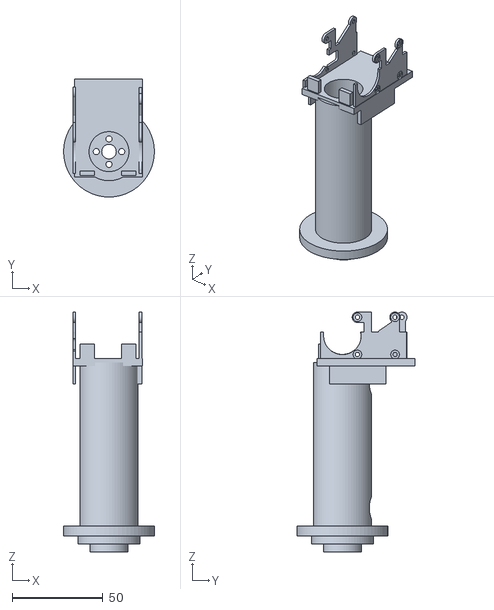
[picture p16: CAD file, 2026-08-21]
3d_model/stl/column.stl
50.0 x 65.0 x 132.1

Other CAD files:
3d_model/stl/head_front.stl
3d_model/3mf/cup_components.3mf
3d_model/stl/head_back.stl
3d_model/stl/lid.stl

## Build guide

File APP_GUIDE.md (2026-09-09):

# Health Care Bot Live — 실행 가이드 & 구조

`APP_PLAN.md`(및 화면 분리형 개정판) 기반으로 만든 모바일 웹 앱(PWA)의 실행
방법과 코드 구조를 정리한 문서. 로봇 자체(추론 루프, PTZ 하드웨어)는
`README.md`를 참고하고, 본 문서는 **웹 앱 계층**(`web/` + `src/`에 추가된
API)만 다룬다. "왜 이렇게 만들었나"는 [`web/ARCHITECTURE.md`](web/ARCHITECTURE.md),
의사결정/이슈 히스토리는 [`docs/history/`](docs/history/) ·
[`docs/issues/`](docs/issues/) 참고.

## 1. 한눈에 보는 구조

```
health_care_bot/
├── src/                      # 백엔드 (Python, 기존 추론 루프 + 신규 앱 API)
│   ├── main.py                 추론 루프 진입점 — app_state를 http_server에 연결
│   ├── http_server.py          GET /, /stream.mjpg, /stats.json, /app/*
│   │                           POST /api/ptz, /api/mode, /api/session/*, /api/control/*
│   ├── app_state.py            세션(운동) 상태 + 운영자 PIN 제어권 lock  ← 신규
│   ├── ptz_controller.py       자동 추적 + manual_pan/tilt/center       ← 수정
│   ├── exercise_counter.py     스쿼트/푸시업 rep 카운터 (기존)
│   ├── angles.py / pose_utils.py  각도 계산 / keypoint 유틸 (기존)
│   └── __init__.py             (main.py에 get_cpu_temp_c() 추가 — CPU 온도, 없으면 None)
├── web/                      # 프론트엔드 (Vite + React + TypeScript, PWA)  ← 신규
│   ├── ARCHITECTURE.md        "왜 이렇게 만들었나" — 설계 근거 문서
│   ├── src/
│   │   ├── App.tsx              role 파싱 + 탭 상태 + 상단 헤더(테마 토글 포함) + 네비게이션
│   │   ├── api.ts               백엔드 fetch 래퍼 (client_id 자동 첨부)
│   │   ├── types.ts             stats.json / API 응답 TS 타입
│   │   ├── hooks/
│   │   │   ├── useStats.ts          /stats.json 500ms polling + 연결 상태 판정
│   │   │   ├── useOperatorControl.ts PIN 제어권 claim/heartbeat/해제
│   │   │   ├── useMediaQuery.ts     데스크톱(≥900px) 여부
│   │   │   └── useTheme.ts          Dragonwing(기본)/Reference 테마 전환, localStorage 저장
│   │   ├── screens/
│   │   │   ├── LiveScreen.tsx       라이브 카메라 + 카운트 + 자세 피드백
│   │   │   │                       (FPS/지연/CPU온도/RAM 카드는 데스크톱에서만, 모바일엔 숨김)
│   │   │   ├── ExerciseScreen.tsx   모드 선택 + 세션 진행/결과
│   │   │   ├── CameraControlScreen.tsx  PTZ 조작 (운영자 전용)
│   │   │   └── MoreScreen.tsx       장비상태(전체 텔레메트리)/QR/카메라설정/운동인식설정/앱정보 메뉴
│   │   ├── components/          LiveCamera, PtzPad, ProgressRing, PinModal, QrPanel, InfoRow,
│   │   │                       ThemeToggle, NavBar 등
│   │   └── lib/feedback.ts      각도 기반 실시간 자세 피드백 문구 생성
│   ├── dist/                  `npm run build` 산출물 — 백엔드가 `/app`에서 그대로 서빙
│   └── vite.config.ts         base: '/app/', dev 서버 프록시 설정
├── scripts/
│   └── mock_serve.py         카메라/모델 없이 프론트만 검증할 때 쓰는 목업 백엔드 ← 신규
├── docs/{history,issues}/    의사결정/문제 실시간 기록 (1 사건 1 파일)
└── APP_PLAN.md / health_care_bot_mvp_screen_plan.md   기획 문서 (원본)
```

**핵심 원칙**: 프론트는 정적 파일로 빌드되어 백엔드(`http_server.py`)가 직접
서빙한다. 별도 Node 서버가 배포에 필요 없다 — UNO Q에는 Python 프로세스
하나만 떠 있으면 된다.

## 2. 실행 방법

### 2.1 실기(UNO Q) 배포 — 실제 시연용

```bash
# 최초 1회: 프론트 빌드
cd web
npm install
npm run build          # → web/dist/ 생성

# 백엔드 실행 (컨테이너 안 또는 로컬)
cd ..
python3 src/main.py \
    models/movenet_thunder_int8.tflite \
    --mode auto --camera 0 --serial /dev/ttyACM0 --serve 8080
```

접속 URL:

| 대상 | URL |
|---|---|
| 관람객(viewer) | `http://<UNO_Q_IP>:8080/app` |
| 운영자(operator) | `http://<UNO_Q_IP>:8080/app?role=operator` |
| 디버그 페이지(기존) | `http://<UNO_Q_IP>:8080/` |

운영자 PIN 기본값은 `1234` (`src/app_state.py`의 `_operator_pin`). 실제
시연 전에 반드시 바꿀 것 — `HCB_OPERATOR_PIN=<새 PIN> bash docker/run.sh`
(코드 수정 불필요, 2026-09-09 추가).

`/app`은 커밋된 `web/app/index.html`이 서빙한다(2026-09-09부터). `web/dist`는
React 시안의 빌드 산출물일 뿐이라 없어도 `/app`은 정상이다.

### 2.2 프론트만 따로 개발할 때 (`npm run dev`)

카메라/모델 없이 UI만 빠르게 고칠 때는 Vite dev 서버 + 목업 백엔드 조합을
쓴다.

```bash
# 터미널 1 — 목업 백엔드 (카메라/서보 없이 stats.json/API만 흉내)
python scripts/mock_serve.py          # http://localhost:8090

# 터미널 2 — 프론트 dev 서버 (HMR)
cd web
VITE_BACKEND_URL=http://localhost:8090 npm run dev   # http://localhost:5173
```

`vite.config.ts`가 `/stats.json`, `/stream.mjpg`, `/api/*`를
`VITE_BACKEND_URL`(기본 `http://localhost:8080`)로 프록시하므로 CORS 신경
쓸 필요 없이 `http://localhost:5173/?role=operator`로 바로 접속해 개발하면
된다.

실제 UNO Q가 켜져 있고 같은 네트워크라면 `VITE_BACKEND_URL`을 그 기기의
`http://<UNO_Q_IP>:8080`으로 바꿔서 진짜 카메라 스트림을 보며 개발할 수도
있다.

### 2.3 프론트 수정 후 실기에 반영하기

```bash
cd web && npm run build
```

만으로 끝난다 — `web/dist`만 갱신되면 백엔드 재시작 없이 바로 `/app` 새로고침 시 반영된다 (Python 프로세스는 그대로 두어도 됨).

## 3. 역할(role) & 권한 모델

- URL의 `?role=operator` 유무로 화면에 운영자 전용 탭(카메라 제어)과 버튼을
  보여줄지만 결정한다. **실제 권한 검사는 서버가 한다** — role 파라미터는
  UI 노출 여부일 뿐, 서버 mutation API(`/api/ptz`, `/api/session/*`,
  `/api/mode`)는 전부 `client_id` + 제어권 lock을 확인한다.
- 운영자가 PTZ나 세션을 처음 조작하면 `PinModal`이 뜨고, PIN이 맞으면
  `POST /api/control/claim`으로 60초 lock을 얻는다. 이후 20초마다
  `POST /api/control/heartbeat`로 자동 연장한다 (`useOperatorControl.ts`).
- 다른 기기가 이미 lock을 쥐고 있으면 배지가 "다른 기기가 제어 중"으로
  바뀌고 버튼이 비활성화된다 (`app_state.py::claim_control`의
  `locked_by_other`).

## 4. API 요약

| Method | Path | 설명 | 인증 |
|---|---|---|---|
| GET | `/stats.json` | 추론 상태 + `app.session` / `app.control` / `viewer_count` | 없음 |
| GET | `/stream.mjpg` | MJPEG 라이브 스트림 | 없음 |
| GET | `/app/*` | 빌드된 React 앱 정적 파일 | 없음 |
| POST | `/api/control/claim` | `{client_id, pin}` → 제어권 획득 | PIN |
| POST | `/api/control/heartbeat` | 제어권 60초 연장 | lock 보유자만 |
| POST | `/api/control/release` | 제어권 반납 | lock 보유자만 |
| POST | `/api/ptz` | `{command: pan\|tilt\|center\|auto_track\|stop, delta_deg?}` | lock 필요 |
| POST | `/api/mode` | `{mode: auto\|squat\|pushup}` | lock 필요 |
| POST | `/api/session/start` \| `/pause` \| `/resume` \| `/reset` \| `/finish` | 세션 상태 전이 | lock 필요 |

모든 POST 요청 body에는 `client_id`가 필요하며, `web/src/api.ts`가
`localStorage`에 저장된 client_id를 자동으로 붙인다.

`stats.json`에는 `cpu_temp_c`(SoC 온도, `/sys/class/thermal/thermal_zone0/temp`
읽기 — 없는 환경/Windows에서는 `null`)도 포함된다. 앱에서는 더보기 →
장비 상태, 그리고 데스크톱 화면의 라이브 텔레메트리 카드에서 쓴다.

## 5. 트러블슈팅

| 증상 | 원인 / 조치 |
|---|---|
| `/app` 접속 시 503 `web_not_built` | `cd web && npm run build` 후 재접속 (백엔드 재시작 불필요) |
| PTZ/세션 버튼이 계속 비활성 | 운영자 PIN을 아직 입력 안 했거나 다른 기기가 lock 보유 중 — 상단 배지 확인 |
| 스트림이 "재연결 중"에서 멈춤 | 백엔드(`--serve` 포트)가 실행 중인지, `/stream.mjpg`가 직접 열리는지 확인 |
| dev 서버에서 상태가 안 뜸 | `VITE_BACKEND_URL`이 실제 백엔드(또는 `mock_serve.py`) 주소를 가리키는지 확인 |
| Windows에서 `mock_serve.py` 실행 시 `ModuleNotFoundError: No module named 'cv2'` | conda `(base)` 등 cv2 없는 Python이 잡힌 것. `cv2`가 설치된 인터프리터를 직접 지정해서 실행 (예: `& "C:\...\Python314\python.exe" scripts/mock_serve.py`) 하거나 `pip install opencv-python numpy` |
| Git Bash에서 `adb push`가 "성공" 로그를 내고도 디바이스에 실제로 반영 안 됨 | MSYS가 리모트 경로(`/home/arduino/...`)를 Windows 경로로 잘못 변환하는 문제. **PowerShell로 adb 명령 실행** — 상세: [`docs/issues/2026-07-11_01_adb_push_msys_path_mangling.md`](docs/issues/2026-07-11_01_adb_push_msys_path_mangling.md) |
| `web/dist`를 다시 push했는데 반영이 안 됨 | remote `web/dist`가 이미 있으면 `adb push`가 안에 `web/dist/dist/`로 중첩시킨다. `adb shell "rm -rf .../web/dist"` 먼저 실행 후 push — 상세: [`docs/issues/2026-07-11_02_adb_push_directory_nests_when_remote_exists.md`](docs/issues/2026-07-11_02_adb_push_directory_nests_when_remote_exists.md) |

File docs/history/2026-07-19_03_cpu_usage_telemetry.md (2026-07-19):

# 2026-07-19 — 라이브 화면 CPU 사용률 표시 + 디바이스 여유 실측

## 시점

2026-07-19. PTZ 관성 추적 작업(`v3`, [`2026-07-19_02`](2026-07-19_02_ptz_time_based_control_and_loss_recovery.md))
을 마치고 웹 UI를 손본 첫 작업.

## 사건

메인 라이브 화면 텔레메트리에 **CPU 사용률 카드**를 추가했다. 기존에 FPS /
지연 / CPU 온도 / RAM 4개가 있었으나 **사용률은 없었다** — 온도는 있는데
"얼마나 쓰고 있나"는 볼 수 없는 상태였다.

작업 중 **디바이스 CPU가 이미 83%** 라는 것이 실측으로 드러났다.

## 배경 — 왜 필요했나

디바이스가 11 FPS로 동작하는데, 이게 "인식 모델이 무거워서"인지 "다른 데서
CPU를 먹고 있어서"인지 구분할 지표가 없었다. `cpu_temp_c`는 발열만 보여주지
부하 여유를 알려주지 않는다.

## 구현

### 백엔드 — psutil 없이 `/proc/stat` 차분

기존 `get_rss_mb()` / `get_cpu_temp_c()`가 `/proc`을 직접 읽는 패턴을 그대로
따랐다. `requirements.txt`에 의존성을 추가하지 않기 위함.

```python
def get_cpu_percent():
    """시스템 전체 CPU 사용률 0~100 (전 코어 합산을 100%로 정규화)."""
```

**주의할 점 두 가지:**

1. **`/proc/stat`은 부팅 이후 누적값**이라 값 하나로는 사용률을 알 수 없다.
   직전 호출과의 차분으로 구간 사용률을 낸다 → **첫 호출은 항상 `None`**.
   프론트는 이때 `—`를 표시한다.
2. **컨테이너 안에서도 `/proc/stat`은 호스트 전체 값**을 보여준다(procfs가
   네임스페이스로 분리되지 않음). 따라서 이 값은 **디바이스 전체 부하**이지
   이 프로세스만의 사용률이 아니다. 의도한 동작이다 — "100% 기준으로 얼마나
   쓰고 있나"를 보려면 전체 부하가 맞다.

### 프론트엔드

- `Stats` 타입에 `cpu_percent: number | null` 추가
- 텔레메트리 그리드 4칸 -> 5칸, CPU 카드 신설
- **100% 기준 채움 막대**를 같이 둠 — 숫자만으로는 여유가 얼마나 남았는지
  가늠이 안 된다. 부하 구간별로 색이 바뀐다:

| 구간 | 색 (기존 디자인 토큰) |
|---|---|
| ~70% | `--success` |
| 70~90% | `--warning` |
| 90%~ | `--danger` |

- `role="meter"` + `aria-valuenow` 로 접근성 처리

## 결과 — 검증

**`vmstat`으로 교차 확인해 계산이 맞는지 검증했다.**

```
vmstat:  us=76  sy=7  id=16   ->  사용률 = 100 - 16 = 84%
stats.json:  cpu_percent = 82~83%
```

1~2%p 차이는 샘플링 시점 차이 범위. 계산식이 맞다.

`nproc` = 4 (4코어). 표시값은 전 코어 합산을 100%로 정규화한 것.

## 중요 관측 — 디바이스 여유가 17%뿐이다

**측정 시점 CPU 83%.** 추론(MoveNet Thunder INT8, 11 FPS, 4스레드)과 MJPEG
인코딩이 대부분을 쓰고 있다. **이미 warning 구간(70~90%)이다.**

앞으로 기능을 추가할 때 반드시 참고해야 할 수치다. 특히:

- FPS를 올리려는 시도는 CPU 여유가 없어 한계가 있다
- MCU 트랙(보류 중)이나 KWS 같은 추가 워크로드를 얹으면 이 17%를 나눠 써야 한다
- 발열(51도)은 아직 여유가 있으나 지속 부하 시 재확인 필요

## 알려진 제약

**이 카드는 900px 이상에서만 보인다.** 기존 텔레메트리 행
(`.hcb-live__telemetry`)이 `display: none`이고 데스크톱 미디어 쿼리에서만
그리드로 뜨는 구조라, CPU 카드도 같은 규칙을 따른다. **폰으로 `/app`을 열면
보이지 않는다.** 모바일 노출이 필요하면 별도 작업이 필요하다.

## 다음 단계

- 모바일에서도 CPU를 보이게 할지 결정 (현재는 데스크톱 전용)
- 지속 부하 상태에서 온도 추이 관찰 (현재 51도)

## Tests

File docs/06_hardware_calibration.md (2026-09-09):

# 하드웨어 현재값 · 캘리브레이션 / 재조립 절차

본 문서는 짐벌·서보의 **현재 확정값**과, 재조립·재배선했을 때 그 값을 다시 세우는 절차를
정리합니다. 여기 적힌 값은 전부 **지금의 물리적 장착 상태에 의존**하므로, 기구부를 건드렸다면
§4를 반드시 거쳐야 합니다.

구현: [`src/st3215_bus.py`](../src/st3215_bus.py) ·
[`scripts/calibrate_st3215.py`](../scripts/calibrate_st3215.py) ·
[`scripts/test_st3215_serial.py`](../scripts/test_st3215_serial.py)

## 0. 한 눈에 — 현재 확정값

| 항목 | 값 | 근거 |
|---|---|---|
| yaw 서보 (좌우) | **ID = 1** (체인 첫 번째) — **베이스에 장착** | 2026-07-16 |
| pitch 서보 (상하) | **ID = 2** (yaw에서 데이지체인) — **헤드에 장착** | 2026-07-16 |
| 중앙 기준 | tick **2047 = 180°** (EEPROM Homing_Offset 캘리브레이션) | 2026-07-17 |
| yaw 가동범위 | **90 ~ 270°** (중앙 ±90) | 2026-07-17 실측 |
| pitch 가동범위 | **150 ~ 210°** (중앙 ±30) | 2026-07-17 실측 |
| pitch 방향 | 현재 장착 상태에서는 **`pitch_sign=-1`이 정상** (2026-08-07 재조립 후 확정) | 2026-08-07 실측 |
| yaw 방향 | 기본값 `yaw_sign=+1`이 정상 | 2026-07-19 실기 |
| 회전 속도 | 569 tick/s ≈ 50 deg/s (옛 PWM 20 ms/° 등가) | 안전상 고정 |
| 버스 | 1,000,000 baud, half-duplex 3선(VCC/GND/DATA) | |
| 포트 | 디바이스 `/dev/ttyACM0` (CH343, CDC-ACM) / PC `COM9` | |

Homing_Offset 실측 이력 (참고 — **최신이 유효**):

| 시점 | yaw(ID=1) | pitch(ID=2) | 비고 |
|---|---|---|---|
| 2026-07-17 | -1117 | -713 | 최초 캘리브레이션 |
| **2026-07-21** | **-492** | **-1341** | 재조립 후 재캘리브레이션 (현재) |

값이 달라진 것은 그새 서보가 다른 물리 자세로 재조립됐기 때문이다 — **오프셋 값 자체를
문서에서 베껴 쓰지 말고, 절차(§4)로 다시 세울 것.**

### 0-1. 두 모터가 어디에 있나

혼동하기 쉬워서 적어둔다 — **모터가 한곳에 모여 있지 않다.**

| | 들어 있는 것 |
|---|---|
| **헤드**(위쪽 육각 통) | 카메라 + **pitch(상하) 서보 ID=2** |
| **기둥** | 두 통을 잇는 축. pitch 관절이 붙고, 데이지체인 케이블이 이 안으로 지난다 |
| **베이스**(아래쪽 육각 통) | **yaw(좌우) 서보 ID=1** + UNO Q + 셀프파워 허브 + Bus Servo Adapter |

그래서 **yaw는 헤드+기둥 전체를 돌리고, pitch는 헤드만 끄덕인다.**

서보 버스(데이지체인) 케이블은 **기둥 안으로 지난다.** 실물 사진
([`assets/robot.jpg`](assets/robot.jpg))에서 헤드-베이스 사이에 바깥으로 나온 루프가
보이는데, 이건 배선이 새는 게 아니라 **회전 여유를 주려고 일부러 밖으로 빼둔 여유분**이다.

> **이 여유분을 정리하거나 타이로 묶지 말 것.** 여유가 없으면 yaw가 돌 때 케이블이
> 당겨진다.

가동범위가 비대칭인 것(yaw ±90 / pitch ±30)은 **실측으로 정한 값**이고(§0, 2026-07-17),
이 문서는 그 원인을 규명하지 않았다. 기구부를 바꿨으면 원인을 추측하지 말고 §4-5 절차로
다시 재는 것이 맞다.

토크를 내리면(`calibrate_st3215.py stop`) pitch 서보가 헤드 무게를 직접 받는 구조라
**헤드가 처질 수 있다.** 분해·재조립 전에는 헤드를 손으로 받치고 내릴 것.

## 1. 구성 / 배선

```
[셀프파워 USB 허브] ─── [Bus Servo Adapter (CH343)] ─── [yaw ID=1] ─── [pitch ID=2]
                                    │                    (데이지체인)
                          서보 전원은 어댑터 배럴잭 (6~12.6V, USB와 별개)
```

- 어댑터↔MCU 배선은 **3가닥 단선 half-duplex**다(TX/RX 별도 2선이 아님). 다만 **현재
  런타임은 MCU를 경유하지 않는다** — Linux가 pyserial로 직접 구동한다
  ([`00`](00_project_blueprint.md) §2-2).
- **서보 전원(6~12.6V)은 USB와 별개다.** 전원이 없으면 포트는 정상으로 열리는데 ID 1~5가
  전부 무응답이 된다 → COM 포트/ID 문제로 오해하기 쉽다. **어댑터 배럴잭을 먼저 확인.**
- **UNO Q는 USB 호스트 VBUS를 공급하지 않는다** → 셀프파워 허브 필수
  ([`08_troubleshooting.md`](08_troubleshooting.md) §3).

> **서보 CAD(STEP)는 리포에 두지 않는다.** 하우징 설계 때 치수를 맞추려면 ST3215의 3D
> 모델이 필요한데, 이건 서보 제조사가 자사 제품용으로 배포하는 도면이라 우리 리포에
> 재배포할 성질이 아니다. **필요할 때 제조사/판매처 제품 페이지에서 직접 받아 로컬에서만
> 쓴다.** `.gitignore`가 `*.step`을 막고 있으므로 실수로 커밋되지 않는다.
> 참고: `3d_model/`의 STL·3MF·preview는 전부 `3d_model/source/gen_stl_v8_43_complete.py`가 만드는
> 자체 산출물이라 STEP 없이도 빌드된다.

## 2. 왜 EEPROM 중앙 재정의를 쓰는가

raw tick이 물리 중앙에서 벗어나 있으면(캘리브레이션 전 yaw는 3590대였다) 포지션
모드(단일회전 0~4095)에서 한쪽 방향 여유가 부족해진다 — 그때는 +44°밖에 남지 않았다.
EEPROM에서 진짜 중앙(tick 2047)으로 재정의해야 **양쪽 ±90° 여유가 다 확보**되고 멀티턴 모드
없이 필요한 범위가 들어온다.

"raw tick을 코드 상수로만 박아넣기"를 택하지 않은 이유가 이것이다.

## 3. 절대 하지 말 것 — 사고 이력

**torque가 켜진 상태에서 `Homing_Offset`(또는 위치 관련 EEPROM)을 바꾸지 말 것.**

`Present_Position = Actual_Position - Homing_Offset` 관계상 오프셋을 바꾸면
Present_Position이 순간적으로 크게 달라진 것처럼 보인다. 위치 제어 루프가 켜져 있으면
(`Torque_Enable=1`) 서보가 이전 `Goal_Position`과의 오차를 **실제 회전으로 메우려 하면서 큰
폭으로 돌아간다.** 2026-07-17에 이 실수로 **3D 프린트 짐벌 하우징이 파손**됐다.

같은 사고에서 드러난 두 번째 함정:

> **STS3215는 레지스터마다 부호비트 위치가 다르다.**
> `Homing_Offset`(addr 31) = **bit11**, `Present_Position`(addr 56) = **bit15**.
> 양수 값은 두 방식이 우연히 같은 값을 내서 정상처럼 보이지만, **음수 값을 쓰면 완전히 다른
> raw 값**이 저장되어 서보가 엉뚱한 오프셋으로 해석한다.

현재 `scripts/calibrate_st3215.py`의 `calibrate`가 **torque≠0이면 즉시 예외로 중단**하고,
부호비트를 레지스터별로 분리해 인코딩한다. **수동으로 EEPROM을 조작하지 말고 이 명령을 쓸 것.**

상세: [`issues/2026-07-17_01`](issues/2026-07-17_01_homing_offset_wrong_sign_bit_caused_physical_snap.md)

## 4. 재조립 후 확인 절차

짐벌을 분해했다 다시 조립했거나 서보를 교체·재배선했을 때 반드시 거친다.
**§0 표의 값(중앙·방향·ID·가동범위)이 전부 틀어질 수 있다.**

특히 **회전 방향**이 그렇다. "180에서 줄어들면 카메라가 위"는 2026-07-19에 실측한 값이지
코드나 서보의 고유 성질이 아니다. 피치 서보를 반대로 달면 정확히 반대가 된다.

값 자체보다 **확인 절차**를 남겨두는 이유가 이것이다. 검사는 아주 싸다 — 추적을 돌릴
필요도, 사람이 프레임에 있을 필요도 없다.

> **순서가 중요하다: `calibrate` → 방향 확인.**
> `calibrate`는 중앙 기준(EEPROM `Homing_Offset`)을 다시 정의한다. 방향 확인을 먼저 하면
> `150`이 가리키는 물리 각도가 그 뒤에 달라져 버려 검사가 무의미해진다.

### 4-1. 중앙 재정의

짐벌을 **원하는 정면 자세로 손으로 맞춰둔 뒤** 실행한다. 이 명령은 서보를 움직이지 않고
"지금 이 자세"를 중앙(tick 2047 = 180°)으로 재정의한다.

```powershell
# 개발 PC
py -3.14 scripts/calibrate_st3215.py --port COM9 calibrate
```

```bash
# 디바이스에서 직접 (호스트 python3에는 pyserial이 없어 전용 venv를 쓴다)
cd ~/health_care_bot
~/.venvs/hcb/bin/python scripts/calibrate_st3215.py --port /dev/ttyACM0 calibrate
```

`calibrate`가 torque off → 계산 → goal 동기화 → torque on 순서를 자동 처리한다.

**긴급정지**(다른 터미널에서, `move` 도중에도 가능):

```powershell
py -3.14 scripts/calibrate_st3215.py --port COM9 stop     # torque 즉시 OFF
```

### 4-2. pitch 방향 확인

한계각으로 보내고 **눈으로 본다.**

```powershell
py -3.14 scripts/test_st3215_serial.py --port COM9 --id 2 move 150
```

| 카메라가 향하는 곳 | 조치 |
|---|---|
| **위** | `pitch_sign = -1` 유지 (**현재 기본값**) |
| **아래** | `src/ptz_controller.py`의 `pitch_sign` 기본값을 `+1`로 (또는 `--pitch-sign 1`) |

`run.sh`는 `PITCH_SIGN` 환경변수로도 받는다(기본 `-1`): `PITCH_SIGN=1 bash docker/run.sh`.
기동 로그의 `sign : yaw=1 pitch=-1` 줄에서 실제 적용값을 확인할 수 있다.

확인 후 중앙으로 되돌린다: `move 180`

### 4-3. yaw 방향 확인

```powershell
py -3.14 scripts/test_st3215_serial.py --port COM9 --id 1 move 90
```

카메라가 예상과 반대로 돌면 `yaw_sign`을 뒤집는다. 확인 후 `move 180`.

### 4-4. ID 매핑 확인

데이지체인 순서가 바뀌었을 수 있다.

```powershell
py -3.14 scripts/test_st3215_serial.py --port COM9 --id 1 ping
py -3.14 scripts/test_st3215_serial.py --port COM9 --id 2 ping
```

기대값: **ID 1 = yaw(체인 첫 번째), ID 2 = pitch**. 다르면 `ptz_controller.py`의
`yaw_id`/`pitch_id`를 맞추거나 `set-id`로 재지정한다.

> **ST3215는 공장 출하 ID가 모두 1이다.** 체인에 물리기 전에 낱개로 1/2를 나눠 기록해야
> 한다(그대로 체인하면 버스 ID 충돌로 무응답).
> **`set-id`는 즉시 반영된다** — "전원 재투입 필요"라는 일반 SDK 문구와 다르다. 실패 로그가
> 떠도 새 ID로 `ping`해서 실제 상태를 확인할 것
> ([`issues/2026-07-16_01`](issues/2026-07-16_01_servo_id_change_takes_effect_immediately.md)).

### 4-5. 가동범위 재실측

기구부가 바뀌었으면 소프트리밋도 갱신해야 한다. 손으로 천천히 한계까지 돌려보고 각도를 읽는다.

```powershell
py -3.14 scripts/test_st3215_serial.py --port COM9 --id 1 read
```

| 축 | 현재 범위 | 코드 필드 |
|---|---|---|
| yaw | 90 ~ 270° | `yaw_min` / `yaw_max` |
| pitch | 150 ~ 210° | `pitch_min` / `pitch_max` |

**새 범위가 더 좁아졌는데 소프트리밋을 그대로 두면 서보가 기구부에 부딪히며 계속
밀어붙인다.** 반드시 갱신할 것.

## 5. 요약 체크리스트

- [ ] 짐벌을 정면 자세로 맞춘 뒤 `calibrate` 실행 (§4-1)
- [ ] pitch 방향 확인 (`--id 2 move 150` → 위를 보는가) (§4-2)
- [ ] yaw 방향 확인 (`--id 1 move 90`) (§4-3)
- [ ] ID 매핑 확인 (`ping` — yaw=1, pitch=2) (§4-4)
- [ ] 가동범위 재실측 후 소프트리밋 갱신 (§4-5)
- [ ] 확인된 값으로 **본 문서 §0 표를 갱신**

## 6. 벤치 도구 요약

| 스크립트 | 서브커맨드 | 용도 |
|---|---|---|
| `scripts/calibrate_st3215.py` | `calibrate` | ID 1·2 전체 중앙 재정의 (torque off/계산/goal 동기화/on 자동) |
| | `set-center` | 서보 하나만 |
| | `stop` | 긴급정지 (torque 즉시 OFF) |
| `scripts/test_st3215_serial.py` | `ping` / `read` | 응답·위치·전압·온도 확인 |
| | `move` / `sweep` | 단발 이동 / 왕복 |
| | `set-id` | ID 변경 (즉시 반영) |
| | `dual-spin` | 휠 모드 연속 회전 (체인 검증용) |

레지스터 주소·부호비트는 huggingface/lerobot의 feetech 구현으로 검증했다. 새 레지스터를
다룰 때는 **매번 그 테이블과 대조**하고, 이 프로젝트 문서 없이 register map을 추측하지 않는다.

## 7. 관련 문서

- 서보 안전 규칙이 코드에 어떻게 박혀 있는지: [`01_architecture.md`](01_architecture.md) §5-1
- 소프트리밋을 쓰는 추적 로직: [`03_algorithm_ptz_tracking.md`](03_algorithm_ptz_tracking.md) §8
- 사고·함정 원본: [`issues/2026-07-17_01`](issues/2026-07-17_01_homing_offset_wrong_sign_bit_caused_physical_snap.md) ·
  [`issues/2026-07-16_01`](issues/2026-07-16_01_servo_id_change_takes_effect_immediately.md)
- 캘리브레이션·실측 경위: [`history/2026-07-17_01`](history/2026-07-17_01_yaw_pitch_center_calibration_completed.md) ·
  [`history/2026-07-17_02`](history/2026-07-17_02_yaw_pitch_range_of_motion_measured.md) ·
  [`history/2026-07-16_01`](history/2026-07-16_01_st3215_bench_test_tool_and_daisy_chain_verification.md)

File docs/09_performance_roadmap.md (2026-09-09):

# 성능 실측 · 로드맵

본 문서는 "왜 11 FPS인가"에 대한 실측 근거와, 올릴 수 있는 방법을 효과 순으로 정리합니다.
그리고 지금 남아 있는 할 일의 우선순위를 담습니다. 추측을 배제하고 **측정된 것만** 적습니다.

## 0. 한 눈에

| 항목 | 실측 | 측정 시점 |
|---|---|---|
| e2e FPS | **11.3** (10.5~11.6) | **2026-09-08 재측정** |
| 루프 지연 `loop_ms` | ~90 ms (84.8~129.8) | 2026-09-08 |
| CPU 사용률 (4코어 합산 100% 기준) | **~84%** (78.4~86.5, `vmstat` 교차검증 84%) | 2026-09-08 |
| CPU 클럭 | 4코어 전부 **2016 MHz = 최대** | schedutil이 이미 최대까지 밀어붙임 (2026-09-08 재확인) |
| CPU 명령셋 | `asimd`만, **`asimddp`(INT8 dotprod) 없음** | 2026-09-08 `/proc/cpuinfo` 재확인 |
| RSS | **~101 MB** (과거 문서값 215 MB는 폐기) | 2026-09-08 |
| SoC 온도 | 60°C(기동 30분 이내) / 과거 최고 73°C(추론 지속) | throttle 전 |
| dropped_frames | 0 | 2026-09-08 |

> 2026-09-08 측정 조건: 컨테이너 기동 후 `/stats.json` 2초 간격 15회 폴링, 뷰어 0명,
> 사람 없음. `docker stats` 기준 컨테이너 메모리는 53.8 MiB.
> **RSS만 과거값과 2배 차이가 났고 나머지는 전부 기존 서술 범위와 일치했다.**

**결론: 시스템은 invoke(추론) 바운드다.** 모델을 안 바꾸면 유일한 큰 레버는 NPU 델리게이트다.

## 1. 왜 FPS가 안 오르나

### 1-1. 실험과 결과

| 실험 | 결과 |
|---|---|
| 인코딩 ON(`--serve 8080`) vs OFF(`--serve 0`) | 11.34 ↔ 11.41 FPS = **차이 ~0** (오차 범위) |
| 카메라 15 fps 캡 시도 | 카메라가 무시(actual 30.5 유지) → 비교 불가 |
| CPU 거버너 | 이미 최대 클럭 → 여지 없음 |

### 1-2. 왜 화면을 꺼도 안 오르나

루프가 `grab → invoke → draw → encode` **직렬**이고, 구간마다 코어 사용이 다르다:

```
invoke 구간        : 4코어 100%  ← 여기가 대부분의 시간
draw/encode 구간   : 1코어만 (3코어 유휴)
                     → 평균 CPU가 ~85%로 보이는 이유
```

화면/인코딩을 끄면 사라지는 것은 "3코어가 노는 짧은 꼬리"다. **invoke가 쓸 수 있는 코어를
늘려주지 못하므로** FPS가 안 오른다. 병목은 invoke 지연 그 자체이고, 남는 15%는 invoke가 쓸
수 없는 단일스레드 유휴다.

## 2. 올리는 방법 (효과 순)

| # | 방법 | 기대 | 상태 |
|---|---|---|---|
| 1 | **NPU/DSP 델리게이트** (Qualcomm Hexagon HTP · QNN/LiteRT) | **큼** — INT8 전용 하드웨어로 오프로드하면 CPU도 풀린다 | **미착수 (최우선)** |
| 2 | Adreno GPU 델리게이트 | 애매 — GPU는 FP16 선호, INT8엔 불리 | 미검토 |
| 3 | 클럭/거버너 | 없음 — 이미 최대 | 확인 완료 |
| 4 | 발열 관리 | 부스트 아님 — soak에서 클럭 유지용 | — |
| 5 | 스레드/파이프라인 (draw·encode를 다음 invoke와 겹침) | 소폭 ~10%, 복잡도↑ | 미착수 |
| — | 모델 교체 (Thunder → Lightning) | 큼 | **사용자 지시로 제외** |

### 2-1. NPU 델리게이트 — 착수 지점

CPU에 `asimddp`가 없어 INT8 고속 커널을 못 쓰는 상황이므로, INT8 전용 하드웨어로 넘기는 것이
정공법이다. 다음 세션에서 확인할 것:

1. 디바이스에 **Hexagon/QNN 라이브러리가 있는지** (`libQnn*` 계열 탐색)
2. `ai_edge_litert`의 **델리게이트 API**로 붙일 수 있는지
3. **AI Hub QNN 컴파일 모델이 필요한지** (현재 TFLite INT8을 그대로 쓸 수 있는지)

정확도를 버리지 않고 FPS를 올리는 유일한 경로라 우선순위가 가장 높다.

## 3. `--idle-skip-draw` — 검증된 소폭 이득

**스트림 뷰어가 0명일 때** draw+encode를 통째로 건너뛰는 opt-in 플래그.

| 모드 | FPS |
|---|---|
| 비게이팅 (기본) | ~11.34 |
| 게이팅 (뷰어 0명, 인코딩 skip) | **~11.44** (11.2~11.6, 변동 감소) |

**이득 ~0.1~0.3 fps + 안정화** — 예측한 "소폭"과 일치한다. 천장 ~11.4는 invoke 바운드 그대로다.
정확도 손해 0이고, 플래그가 없으면 기존과 100% 동일하게 항상 그린다.

> 이 결과로, "스트리밍 온/오프 게이팅으로 성능을 얻는다"는 방향은 **실익이 ~0으로 확인**됐다.
> 관련해 승인받아 뒀던 별도 계획은 사실상 폐기 권고 상태다.

## 4. CPU · 발열 여유

**측정 시점 CPU ~84%** — 추론(MoveNet Thunder INT8, 11 FPS, 4스레드)과 MJPEG 인코딩이 대부분을
쓰고 있고 **이미 warning 구간(70~90%)이다.** 앞으로 기능을 얹을 때 반드시 참고할 수치다:

- FPS를 올리려는 시도는 CPU 여유가 없어 한계가 있다.
- MCU 트랙(보류)이나 KWS 같은 추가 워크로드를 얹으면 **이 16%를 나눠 써야 한다.**
- 온도는 추론 지속 시 73°C까지 올라간다(throttle 전). **soak(장시간) 측정은 아직 안 했다.**

> `cpu_percent`는 컨테이너 안에서도 **호스트 전체 부하**다(procfs 네임스페이스 미분리).
> 이 프로세스만의 사용률이 아니다 — [`02`](02_http_api_and_stats.md) §4.

## 5. 다음 할 일 우선순위

### 5-0. 2026-08-08 이후 미해결로 넘어온 것

| # | 항목 | 내용 |
|---|---|---|
| 0-1 | **스쿼트↔숄더프레스 전환 시 pitch 범위** | 무릎-어깨 각도차가 ±30° 범위를 거의 끝까지 써서, 카메라-사람 거리가 가까우면 전환 중 사람을 놓칠 수 있다. 사람이 더 멀리 서서 재테스트 필요 → [`03`](03_algorithm_ptz_tracking.md) §12 |
| 0-2 | **동시 뷰어 2명 이상에서 FPS 저하** | PC+폰 동시 접속에서 10 → 8 관측. Python GIL 스레드 경합 + Funnel 암호화 오버헤드 추정. `--jpeg-quality`를 낮추는 게 쉬운 완화책이나 `run.sh`에 옵션 미노출 |
| 0-3 | **`captures/` 자동 정리 없음** | 경비 모드 사진이 무한히 쌓인다. 2026-09-08 기준 207장 / 17 MB, 루트 파티션 73% 사용 → [`07`](07_runbook.md) §9 |

### 5-1. 실측이 필요한 것 (코드 작업 아님, 최우선)

1. **운동 3종을 실제 사람으로 카운팅 검증 + 임계 튜닝** — 현재 값은 합리적 기본값일 뿐이다.
   누락/중복을 보고 조정한다. 스쿼트는 **발목까지 프레임에 들어오는 거리**에서 해야 각도가
   나온다. 레터럴은 팔꿈치를 곧게, 정면 응시.
2. **PTZ 상체 프레이밍 실측** — 숄더프레스/레터럴에서 머리 위 팔이 프레임에 남는지. 잘리면
   `ptz_controller.py::pitch_target_y_upper`를 0.64 → 0.68~0.72로.
3. **스쿼트 회귀 확인** — 종목 개편·추적 분리 이후에도 종전과 동일하게 추적·카운트되는지.
4. **검출 안정성** — `ptz=lost`가 8초 연속 나온 구간의 원인(거리/화각/조명)을 `/app` 프레이밍
   화면으로 좁힌다.

### 5-2. 그다음

5. **NPU 델리게이트 가능성 조사** (§2-1)
6. ~~웹 계층 확정~~ — **2026-09-08 Fluid로 확정.** 남은 일은 결정이 아니라 정리다:
   보관된 `web/src/` React 계층과 `web/DESIGN.md`·`APP_GUIDE.md`를 지울지 남길지
7. soak(장시간) 측정 — 온도 추이와 클럭 유지 확인

### 5-3. 알려진 부채 (판단 필요)

| 항목 | 내용 |
|---|---|
| **스쿼트 2샘플 rep** | 검출이 끊긴 구간에서 가짜 rep이 성립한다. 후보: DOWN 구간에 유효 샘플 N개 요구 → [`04`](04_algorithm_exercise.md) §6 |
| **`coast_frames`가 프레임 기준** | 시간 기준(`coast_duration_s`)으로 바꾸고 감쇠도 시간당으로 환산 → [`03`](03_algorithm_ptz_tracking.md) §12 |
| `coast_fov_deg` 추정값 | 60°는 실측이 아니다. 보정법은 [`03`](03_algorithm_ptz_tracking.md) §11 |
| ~~**Dockerfile CMD 낡음**~~ | **해소(2026-09-09)** — `--mode squat`로 정정 |
| **PTZ 쿨다운 기본값이 두 군데** | `ptz_controller.py`의 80 ms는 죽은 값이고 `main.py` CLI의 250 ms가 실동작값이다. 코드만 읽으면 오해한다 → [`03`](03_algorithm_ptz_tracking.md) §7 |
| ~~**`scripts/mock_serve.py` 깨짐**~~ | **해소(2026-09-09)** — 카운터 3종으로 교체, 기동 확인 |
| 서보 실제각 미확인 | 목표각과 어긋나도 감지 못 함 |
| 다중 접속 부하 | `/stream.mjpg`가 커넥션당 스레드 1개 점유. 실측 안 됨 |

## 6. 보류 / 기각된 방향

| 항목 | 판단 |
|---|---|
| 모델 교체 (Thunder → Lightning) | **사용자 지시로 제외** |
| 스트리밍 게이팅으로 성능 확보 | 실측 이득 ~0 → 사실상 폐기 (§3) |
| MCU 듀얼브레인 트랙 | JDIGITAL UART가 Router Bridge와 같은 페리페럴이라 서보에 주려면 Bridge(Linux→MCU 명령 통로)를 포기해야 하는 자기모순 → **잠정 보류**(2026-08-08 재검토: "불가능"이 아니라 "이 용도로는 자멸적" — [`00`](00_project_blueprint.md) §2-2) |
| 관성 등속 전환 | overshoot·FPS 의존 증가, 급정거 → 기각 |
| 해부학 범위/좌우 불일치 게이트 | 검출률만 떨어뜨리고 근본 원인 못 잡음 → 기각 |

## 7. 관련 히스토리

- [`history/2026-07-21_02`](history/2026-07-21_02_session_handoff.md) — 성능 조사 결론(§1·§2)의 1차 출처
- [`history/2026-07-19_03`](history/2026-07-19_03_cpu_usage_telemetry.md) — CPU 사용률 계측 추가 + 83% 발견
- [`history/2026-07-15_01`](history/2026-07-15_01_framegrabber_verified_latency_fixed_fps_unchanged.md) — 지연과 FPS가 다른 지표임을 실측
- [`history/2026-08-08_01`](history/2026-08-08_01_session_handoff.md) — **최신 세션 맥락과 남은 일**
- [`history/2026-07-26_05`](history/2026-07-26_05_session_handoff.md) — 그 이전 세션 맥락

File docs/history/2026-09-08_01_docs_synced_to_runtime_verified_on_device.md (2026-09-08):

# 2026-09-08 상설 문서(00~09) 정합성 점검 · 실기 검증 후 동기화

## 1. 한 줄 요약

상설 문서 10종을 코드와 대조하고 **UNO Q 실기에서 직접 재측정**해, 어긋난 값을 전부
런타임 기준으로 맞췄다. 8월 7~8일 경비 모드 작업이 README에만 반영돼 있고 상설
문서에는 `02`를 빼고 전혀 없던 것이 가장 큰 구멍이었다.

## 2. 왜 했나

`docs/`가 "지금 어떻게 동작하는가"를 담기로 한 문서군인데, 경비 모드 커밋(`d961be5`)
이후 README와 `02`만 갱신되고 나머지 8개가 7월 말 상태로 멈춰 있었다.

## 3. 실기 검증 (192.168.0.50)

컨테이너를 띄우고 라이브 `stats.json`·API·로그로 확인했다. **디바이스 `src/`·`docker/`·
`web/dist/index.html`은 리포와 md5 전부 동일**해서, 관측값을 그대로 문서에 쓸 수 있었다.

| 확인 | 결과 |
|---|---|
| e2e FPS / loop_ms | 11.3 (10.5~11.6) / 90.3 ms — 기존 서술과 일치 |
| CPU / 온도 / dropped | 83.8% / 60.4°C / 0 — 일치 |
| **RSS** | **~101 MB** — 문서의 215 MB와 2배 차이. 재측정값 채택 |
| CPU 클럭·명령셋 | 4코어 2016 MHz, `asimd` 있고 `asimddp` 없음 — 문서 정확 |
| 모델 파일 | 7,126,768 B (6.80 MB) — 문서 정확 |
| **PTZ 쿨다운** | 컨테이너 실행 인자에 `--ptz-cooldown-ms` 없음 → **250 ms가 실동작값** |
| pitch 부호 | 기동 로그 `sign : yaw=1 pitch=-1` → **-1이 정상** |
| 카메라 노드 | `video0·1`이 카메라, `video2·3`이 Venus — 07-26 관측과 **정반대** |
| HTTP API | 라우트·에러코드·경로탈출 403·CORS 전부 문서대로 |
| 경비 모드 | 전환 시 pan 116.2→180.0 홈 정렬, ~5초 무장, 자동+수동 촬영, 수동은 쿨다운 무시 — 전부 문서대로 |
| captures 누적 | 207장 / 17 MB, 루트 파티션 73% — 자동 정리 없음 확인 |

## 4. 고친 것

**동작과 어긋났던 것**

1. `03` §7 — 쿨다운을 "250 → 80 ms로 고쳤다"고 서술했으나 **실동작은 250 ms**.
   `ptz_controller.py`의 80.0은 `main.py` CLI 기본값 250.0에 덮여 도달하지 않는 죽은
   값이다. 사용자 판단으로 **런타임(250)을 정답으로 두고 문서를 맞췄다.**
2. `06` — `pitch_sign=+1`이 정상이라고 적혀 있던 것을 `-1`로 정정.
3. `05` §9 — "작업본과 배포본이 동일 내용"이 거짓이 돼 있었다. `design_demos/
   live_apple-design.html`(32 KB, 07-26)에는 경비 UI·QR 생성기가 없어, 문서에 적힌
   복원 명령을 그대로 실행하면 8월 작업이 통째로 롤백된다. **경고로 교체하고 복원
   경로를 backup/git으로 바꿨다.**

**경비 모드 서술 추가** — `00`(출력·검증상태·트리) `01`(모듈경계·상태소유권·degrade)
`03`(track_mode guard, §9-3 홈 복귀, 튜닝값) `04`(4번째 모드·프레이밍 표)
`05`(설정 시트·갤러리·QR 런타임 생성) `07`(§9 경비 운영) `08`(증상 색인).

**값 정정** — IP `.45`→`.50`(05·07), RSS 215→101 MB(00·02·09), 웹 32→48 KB,
`stl/`→`3d_model/`, 복원점 3→5개, `ptz` 스키마에 `track_mode`·`guard_at_home` 추가,
카메라 노드 표에 09-08 행 추가, lsusb 허브명 고정 서술 제거.

**추가** — `07` §8 Tailscale Funnel 절차 + "켠 채로 두지 말 것" 경고, `02` §6·`05` §4
보안 모델에 Funnel 예외 명시, `09` §5-0에 08-08 미해결 3건 이관.

## 5. 남긴 판단

- **80 ms로 내리는 것은 코드 변경이므로 하지 않았다.** 필요하면 `run.sh`에
  `--ptz-cooldown-ms 80`을 추가하면 된다(`03` §7에 방법만 적어둠).
- `docker/Dockerfile`의 `--mode auto`는 그대로 뒀다. 이미 `01`·`08`·`09`가 함정으로
  정확히 기술하고 있고 `run.sh` 경로에서는 드러나지 않는다.
- `design_demos/live_apple-design.html`은 지우지 않았다. 옛 시안으로서의 가치는 있고,
  문서에 "복원용 아님" 경고를 붙이는 쪽을 택했다.

## 5-1. 웹 계층을 "확정"으로 못박음 (같은 날 추가 결정)

사용자 판단으로 **Fluid(`web/dist/index.html`)를 확정 UI로 고정**했다. 그동안 문서가
Fluid를 "아직 결정 안 된 후보"로 다루고 있었다 — `09` §5-2에 "Fluid로 굳힐지 React 시안
6종을 정리할지 결정"이 미결 항목으로 남아 있었고, `web/src/versions/registry.ts` 주석도
"확정된 UI가 아니라 검토 중인 후보"라고 적고 있었다. 실기에서 이미 이것만 쓰고 있는데
문서만 유보 상태였던 것.

- `05` 맨 앞에 "Fluid가 확정 UI다(2026-09-08). 후보가 아니라 고정" 명시.
- `web/src/` React 계층은 **보관 계층**으로 격하. `web/DESIGN.md`·`APP_GUIDE.md`도
  "갱신하지 않는 보관물"로 표기(`00` §6-3).
- `09` §5-2의 미결 항목을 "확정됨, 남은 건 결정이 아니라 정리"로 교체.
- `05`의 React 시안 이름을 `registry.ts` 실제 id로 정정 — 문서의 CARE·LIVE는 없고
  실제로는 `rehab`·`session`이다.

### 곁가지로 발견한 것 — `scripts/mock_serve.py`가 깨져 있다

프론트 목업 개발 경로를 문서에 다시 쓰려다 발견했다. 2026-07-26에 삭제된
`PushupCounter`를 import해서 **실행 즉시 `ImportError`가 난다.** `07` §7과 `08` 증상
색인, `09` §5-3 부채 표에 기록만 하고 코드는 고치지 않았다(문서 작업 범위 밖).

참고로 `mock_serve.py`는 `/app`도 서빙하므로, 고치기만 하면 **React·npm 없이
`http://localhost:8090/app`에서 Fluid를 그대로 띄울 수 있다.** `07` §7을 그 흐름 중심으로
다시 썼다.

## 6. 재발 방지

- **문서의 기본값을 코드의 데이터클래스에서만 읽지 말 것.** CLI 인자가 생성자에
  주입되면 그쪽이 이긴다. 실동작값은 `docker inspect`의 실행 인자로 확인한다.
- **"두 파일을 같이 맞춰둔다"는 관례는 검증 없이 문서에 남기면 거짓이 된다.**
  단일 소스를 정하는 편이 낫다 — 이번에 `web/dist/index.html`로 일원화했다.
- 기능을 추가하면 README만 고치고 끝내지 말 것. 상설 문서에 담당 절이 반드시 있다.
- **"검토 중인 후보"라고 써둔 것은 결론이 나면 반드시 회수할 것.** 실기에서는 이미
  Fluid만 쓰고 있는데 문서와 코드 주석이 몇 달째 "후보"라고 말하고 있었다. 유보 표현은
  읽는 사람을 잘못된 선택지 앞에 세운다.
- **문서에 적은 개발 명령은 실제로 한 번 실행해볼 것.** `mock_serve.py`는 종목 개편
  때부터 깨져 있었는데 문서에는 정상 절차로 남아 있었다.

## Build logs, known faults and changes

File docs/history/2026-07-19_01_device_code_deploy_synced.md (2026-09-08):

# 2026-07-19 — 디바이스 코드 동기화 (07-17 PTZ 통합분 반영)

> **[2026-09-08 보안 마스킹]** 공개 리포 노출을 막기 위해 adb serial(기기 고유 식별자)를 가렸다.
> 기록 내용 자체는 바꾸지 않았다. 원칙: [`00`](../00_project_blueprint.md) §7-1.

## 시점

2026-07-19 (PC에서 PTZ 통합 검증 완료 후, UNO Q 실기 배포 준비)

## 사건

adb로 UNO Q(기기 serial은 `adb devices`로 확인)에 접속해 07-15~17 작업분을 push. 코드 동기화만
수행했고 컨테이너 기동은 하지 않음.

## 배경

디바이스 코드가 **07-11/07-14 상태에 멈춰 있었다.** 07-15 이후 작업
(FrameGrabber 지연 수정, ST3215 드라이버, PTZ v1/v2, 웹 파이프라인 통합)이
전혀 반영돼 있지 않았음. 특히:

- `st3215_bus.py`가 **디바이스에 아예 없었다** — `ptz_controller.py`가 import
  하므로 이 상태로 기동했으면 import 에러로 즉시 크래시
- `ptz_controller.py` 8,545 bytes (Jul 11 구버전) → v2 로직 이전
- `pose_utils.py` 3,055 bytes (Jul 5) → 무릎/엉덩이 중심점 헬퍼 없음

## 결과

- `src/`(9개), `docker/`(3개), `scripts/`(8개) push 완료
- **md5로 15개 파일 전부 로컬과 일치 확인** (push 로그만 믿지 않음)
- `web/dist`는 디바이스에 이미 최신본 존재(해시 일치) — 07-11 이후 프론트
  변경 없어 재빌드/재push 불필요
- `models/movenet_thunder_int8.tflite`는 로컬·디바이스 동일(7,126,768) — 미전송
- 디바이스에서 `python3 -m py_compile src/*.py` → `COMPILE OK` (문법만 검증,
  런타임 동작 보장 아님)

기존 함정 2건은 그대로 적용해 회피:
PowerShell로만 실행([`2026-07-11_01`](../issues/2026-07-11_01_adb_push_msys_path_mangling.md)),
디렉토리 push 전 remote `rm -rf`([`2026-07-11_02`](../issues/2026-07-11_02_adb_push_directory_nests_when_remote_exists.md)).

## 실행을 막고 있는 것 (하드웨어, 코드 문제 아님)

기동을 시도하지 않은 이유. 둘 다 07-11과 동일한 상태:

- **UVC 카메라 없음** — `v4l2-ctl --list-devices` 결과 `/dev/video0`·`/dev/video1`은
  Qualcomm Venus 인코더/디코더 노드뿐. 카메라 노드 자체가 없음. 이 상태로
  컨테이너를 띄우면 `cannot open camera`로 즉시 종료된다.
  (adb 연결 중에는 허브를 꽂을 수 없어 카메라를 물리지 못한 상황)
- **서보 어댑터 없음** — `/dev/ttyUSB*`·`/dev/ttyACM*` 둘 다 없음. CH343
  어댑터가 개발 PC의 COM9에 물려 있어 UNO Q 쪽엔 연결돼 있지 않다. PTZ는
  설계대로 disabled 폴백.

## 다음 단계

1. USB 카메라 연결 후 `v4l2-ctl --list-devices`로 `Video Capture` 타입 노드
   확인 (Venus가 0·1을 선점하므로 보통 `/dev/video2` 이상)
2. CH343 어댑터를 UNO Q로 이설 후 `ls /dev/ttyUSB*`로 노드 확인
3. `CAMERA_DEV=/dev/videoN bash docker/run.sh`로 기동, 라이브 스트림 e2e 검증

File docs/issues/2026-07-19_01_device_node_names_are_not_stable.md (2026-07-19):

# 디바이스 노드 이름(`/dev/video*`, `/dev/tty*`)은 고정이 아니다 — 실행 전 매번 확인

## 증상

### 카메라 — 문서에 적힌 규칙이 반대로 뒤집힘

기존 문서(HANDOFF, `docker/run.sh` 주석)에 이렇게 적혀 있었다:

> Qualcomm Venus 코덱이 `/dev/video0`·`video1`을 먼저 차지하므로 보통
> `/dev/video2` 이상이 진짜 카메라

2026-07-19 실측은 **정반대**였다.

```
USB 2.0 Camera: HD USB Camera (usb-xhci-hcd.2.auto-1.2):
        /dev/video0
        /dev/video1

Qualcomm Venus video decoder:  /dev/video2
Qualcomm Venus video encoder:  /dev/video3
```

문서를 믿고 `CAMERA_DEV=/dev/video2`로 기동했다면 Venus 디코더를 카메라로
열려다 실패했을 것이다. `v4l2-ctl -d /dev/video2 --info`로 확인한 결과
드라이버가 `qcom-venus`, Device Caps가 `Video Memory-to-Memory Multiplanar`
였다 — 캡처 장치가 아니다.

| 관측 시점 | USB 카메라 | Venus 코덱 |
|---|---|---|
| 2026-07-11 | (연결 없음) | video0·1 |
| 2026-07-19 | **video0·1** | video2·3 |

### 서보 어댑터 — ttyUSB가 아니라 ttyACM

`run.sh`의 기본값과 문서가 모두 `/dev/ttyUSB0`이었으나, 실제로는
**`/dev/ttyACM0`** 으로 잡힌다. `/dev/ttyUSB*`는 아예 존재하지 않는다.

```
crw-rw---- 1 root dialout 166, 0 Jul 19 03:39 /dev/ttyACM0
```

`lsusb`상 `1a86:55d3 QinHeng Electronics USB Single Serial` (CH343).

## 원인

**노드 번호는 부팅 시 드라이버 등록 순서로 결정된다.** 그 순서는
USB를 어느 포트에 꽂았는지, 어떤 순서로 꽂았는지, 부팅 시점에 무엇이
연결돼 있었는지에 따라 달라진다. 07-11에는 카메라가 연결돼 있지 않아
Venus가 0·1을 가져갔고, 07-19에는 부팅 시점에 카메라가 물려 있어 먼저
등록됐다.

**시리얼은 드라이버 종류의 문제다.** CH343은 vendor 드라이버(ch341 계열)로
잡히면 `ttyUSB`, CDC-ACM 표준 드라이버로 잡히면 `ttyACM`이 된다. UNO Q
커널은 CDC-ACM 쪽이다.

즉 **어느 쪽도 "보통 이 번호"라는 규칙이 성립하지 않는다.** 특정 시점의
관측을 규칙으로 일반화한 것이 원래 문서의 오류였다.

## 영향

- **카메라**: 잘못된 노드를 지정하면 컨테이너가 카메라를 못 열고 즉시 종료
- **서보**: 노드를 못 찾으면 `run.sh`의 `[ -e "${SERIAL_DEV}" ]` 검사에서
  걸러져 `--device` 인자 없이 실행되고, PTZ는 설계대로 disabled로 degrade
  한다. 기동 로그에 `(MISSING — PTZ disabled)`가 출력되기는 하지만 한 줄이라
  놓치기 쉽고, 그대로 계속 실행되므로 "PTZ만 왜 안 되지"로 헤매게 된다

## 해결

**실행 직전에 매번 확인한다. 문서의 번호를 그대로 쓰지 않는다.**

```bash
v4l2-ctl --list-devices          # USB ... Camera 로 표시된 쪽이 진짜 카메라
ls /dev/ttyACM* /dev/ttyUSB*     # 양쪽 다 볼 것
```

`docker/run.sh`도 함께 고쳤다:

- `SERIAL_DEV` 미지정 시 `/dev/ttyACM*` -> `/dev/ttyUSB*` 순으로 **자동 탐색**
- 카메라/시리얼 노드가 없으면 기동 시 **눈에 띄는 경고 블록**을 출력
  (기존의 한 줄짜리 `(MISSING)` 표기는 스크롤에 묻혔다)
- 주석에서 "보통 video2 이상" 규칙을 삭제하고 매번 확인하도록 변경

## 재발 방지

- **디바이스 노드 번호를 문서에 "규칙"으로 적지 않는다.** 특정 시점의 관측은
  관측으로만 기록하고(위 표처럼 날짜와 함께), 판별 방법을 적는다
- 카메라 노드는 번호가 아니라 **`v4l2-ctl --list-devices`의 장치 이름**으로
  식별한다. `Qualcomm Venus`는 코덱이지 카메라가 아니다
- 시리얼은 `ttyACM`/`ttyUSB` **양쪽을 항상 확인**한다
- 기동 후 PTZ가 안 움직이면 하드웨어를 의심하기 전에 **기동 로그의 serial
  줄부터** 본다

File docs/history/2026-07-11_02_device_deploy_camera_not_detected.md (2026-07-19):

# 2026-07-11 — 디바이스 배포 확인 + USB 카메라 미인식 발견

## 시점

2026-07-11 (웹앱 MVP 구현 직후)

## 사건

adb로 실제 UNO Q(`unoq-korea01`)에 접속해 오늘 변경분(백엔드 API + `web/dist`)을
push하고 컨테이너를 기동해 `/app` 정상 서빙을 로그로 확인. 다만 카메라
캡처 단계에서 실패해 컨테이너가 즉시 종료됨.

## 배경

디바이스의 `/home/arduino/health_care_bot/`이 2026-07-05 상태로 멈춰있어
(`app_state.py` 없음, `web/` 폴더 없음, `http_server.py` 132줄 구버전)
오늘 만든 웹앱이 전혀 반영돼 있지 않았다. 실제 동작 확인을 위해 push +
컨테이너 기동까지 진행.

## 결과

- push (adb) 성공, `/app`·`/app?role=operator` URL이 서버 로그에 정상 출력 —
  새 백엔드 코드가 실제 디바이스에서 정상 동작함을 확인
- `docker run`이 `/dev/video0`를 열지 못하고 `ERROR: cannot open camera`로 종료
- `v4l2-ctl --list-devices`로 확인한 결과 `/dev/video0`·`/dev/video1`은 USB
  카메라가 아니라 **Qualcomm Venus 하드웨어 비디오 코덱(디코더/인코더)**
  노드였음 — 즉 USB UVC 카메라가 현재 디바이스에 물려있지 않거나 인식이
  안 된 상태. `unoq-companion-robot/pose` 문서에 이미 기록된 것과 동일한
  증상 패턴 (Venus 코덱 노드 vs UVC 카메라 구분).
- PTZ 시리얼(`/dev/ttyACM0`)도 현재 없음 — PTZ는 정상적으로 disabled 모드로
  fallback (에러 아님, 설계대로 동작).

## 다음 단계

USB 카메라 재연결 + 필요 시 `sudo modprobe -r uvcvideo && sudo modprobe uvcvideo`
후 `v4l2-ctl --list-devices`로 `Video Capture (single-plane)` 타입 노드가
보이는지 재확인. 그 후 컨테이너 재기동해 라이브 스트림 e2e 검증.

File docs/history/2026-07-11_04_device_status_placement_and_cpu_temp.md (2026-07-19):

# 2026-07-11 — 장비 상태 배치 반복 조정 + CPU 온도 필드 추가

## 시점

2026-07-11

## 사건

더보기 화면의 "장비 상태"(연결상태/FPS/추론루프/dropped frames/PTZ
serial/메모리/모델) 정보 배치를 사용자 피드백에 따라 여러 번 조정했고,
그 과정에서 백엔드에 CPU 온도 필드를 새로 추가했다. 최종 상태:

1. **더보기 화면** — "장비 상태"는 원래대로 탭-진입 메뉴 항목 하나로 복귀.
   전체 필드(연결상태/FPS/추론루프(지연)/dropped frames/PTZ serial/메모리/
   **CPU 온도**(신규)/모델)를 그대로 보여준다. "카메라 성능"이라는 별도
   항목으로 쪼갰던 중간 시도는 폐기.
2. **카메라 제어(운영자) 화면** — 한때 장비 상태 전체를 여기로 옮겼었으나
   최종적으로 제거 — PTZ 패드까지만 남는다.
3. **라이브 화면** — FPS/지연(ms)/CPU 온도/RAM 4개를 작은 카드로
   추가했지만 **데스크톱(≥900px)에서만** 보이고 **모바일에서는 숨김**
   (`index.css` `.hcb-live__telemetry`). 모바일은 카메라 + 현재 운동 +
   피드백까지만 유지.

**백엔드 변경**: `src/main.py`에 `get_cpu_temp_c()` 추가 —
`/sys/class/thermal/thermal_zone0/temp`(millidegree C)를 읽어 `stats.json`의
`cpu_temp_c` 필드로 노출. Windows/온도 노드 없는 환경에서는 `None` →
프론트에서 `—`로 표시. `scripts/mock_serve.py`에도 더미값(52.3) 추가.

**프론트 리팩터**: `MoreScreen.tsx`와 `CameraControlScreen.tsx`가 거의
동일한 `Row`/`InfoRow` 컴포넌트를 각자 정의하고 있던 걸
`web/src/components/InfoRow.tsx` 하나로 통합.

## 배경

첫 요청("더보기 항목 하나로 바로 들어가게")을 잘못 해석해 인라인 요약
카드 + "카메라 성능" 분리로 구현했는데, 사용자의 실제 의도는 "장비 상태
전체를 그대로, 제어 탭 아래로"였다. 그렇게 옮긴 뒤 다시 "그냥 더보기로
옮겨줘"로 최종 정정 — 결과적으로 원래 위치(더보기, 탭-진입 패널)로
돌아왔지만, 그 과정에서 CPU 온도 필드가 새로 생겼고 라이브 화면
텔레메트리 카드(데스크톱 전용)가 추가로 붙었다.

## 결과

로컬 mock 백엔드 + Playwright로 모바일/데스크톱 각 화면 스크린샷 확인,
콘솔 에러 0건. adb로 `src/main.py` + `web/dist` 디바이스에 반영 완료
(중첩 디렉토리 함정 발생 → `docs/issues/2026-07-11_02_...md`로 별도 기록).

## 다음 단계

없음 — 이 배치가 최종. 이후 변경 시엔 이 파일을 참고해 "장비 상태는
더보기에 있는 게 맞다"는 걸 재확인할 것.

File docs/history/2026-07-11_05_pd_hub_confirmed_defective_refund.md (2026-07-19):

# 2026-07-11 — PD 허브 데이터 결함 진단 → PC 재연결로 초기화하면 해결됨

## 시점

2026-07-11

## 사건

카메라가 안 잡히던 문제(`docs/issues/2026-07-11_02_device_deploy_camera_not_detected.md`에서
처음 발견)를 SSH로 원격 진단한 끝에, 원인이 카메라가 아니라 **PD 허브가
전원 공급(PD)과 USB 데이터 허브 역할을 동시에 수행하지 못하는 하드웨어/
협상 문제**로 좁혀졌다. 이후 실제로 **허브를 PC에 한번 꽂았다 뺐더니
허브가 초기화(재협상)되면서, 다시 UNO Q에 연결했을 때 카메라가 정상
인식**되는 것을 확인 — 이 재연결 트릭으로 **문제 해결**. 상세 진단 과정과
배제한 가설들은
[`docs/issues/2026-07-11_03_usb_camera_not_detected_via_pd_hub.md`](../issues/2026-07-11_03_usb_camera_not_detected_via_pd_hub.md)
참고.

## 배경

UNO Q는 USB-C 포트가 하나뿐이고(USB-A 등 별도 호스트 포트 없음), 그
포트에 PD 허브를 물려 보드 전원 공급과 카메라 연결을 동시에 하는 구성으로
운용 중이었다. 물리적으로 케이블을 뽑으면 보드 전체가 죽어 SSH 세션도
끊기는 제약 때문에, 재현 테스트 없이 순수 sysfs/dmesg 로그 분석만으로
진단을 진행 — `/sys/class/typec/port0/{power_role,data_role}` 확인으로
보드 쪽 role 협상은 정상임을 먼저 확인했고, 카메라 대신 단순 USB
저장장치로 교차검증해 카메라 특정 문제가 아님을 좁혔다. 같은 허브를 PD
없이 일반 PC에 연결했을 때 데이터가 정상 동작하는 것도 확인 — 허브의
데이터 라인 자체는 멀쩡함을 재확인했다.

## 결과

- **허브가 이상한 상태로 멈춰있을 때 PC에 한 번 물렸다 빼면 초기화되고,
  그 상태로 다시 UNO Q에 꽂으면 카메라가 정상 인식된다.** 매번 재부팅마다
  또는 USB 재연결 시마다 이 증상이 재발할 가능성은 있음 — 완전히 근본
  수정된 하드웨어 결함이라기보다는, 허브가 특정 negotiation 상태에서
  멈추는 걸 PC 재연결이 리셋시켜주는 워크어라운드에 가까움. 재발 시
  같은 방법(PC에 재연결 후 UNO Q로)으로 대응.
- health_care_bot 웹앱(백엔드 API + `web/dist`)은 이미 디바이스에 정상
  배포·기동 확인됨.
- 같은 세션에서 카메라 지연 문제(FPS 10.8, 체감 지연 loop_ms보다 훨씬 김)도
  발견돼 `src/main.py`에 `FrameGrabber`(캡처 전용 스레드, 최신 프레임만
  유지) 적용 + `docker/run.sh`에 `CAMERA_INDEX` 자동 매핑 추가 — 디바이스에
  push 완료, 카메라 재인식 후 실측 필요.

## 다음 단계

카메라가 다시 인식되면: (1) `lsusb`/`v4l2-ctl --list-devices`로 UVC 카메라
노드 확인 → (2) `CAMERA_DEV=/dev/videoN bash docker/run.sh`로 `main.py`
재기동(수정된 FrameGrabber 포함) → (3) `/stats.json`의 `fps`/`loop_ms`로
지연 개선 확인 → (4) 웹앱 `/app`에서 실제 라이브 스트림 체감 지연 e2e 확인
(`docs/history/2026-07-11_01_web_app_mvp_built.md` "다음 단계"와 연결).

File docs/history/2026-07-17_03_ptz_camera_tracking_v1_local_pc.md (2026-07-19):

# 2026-07-17 — PC 로컬 카메라 PTZ 추적 v1 확정 + 백업

## 시점

2026-07-17 (yaw/pitch 캘리브레이션·가동범위 측정
[2026-07-17_02](2026-07-17_02_yaw_pitch_range_of_motion_measured.md) 이어서)

## 사건

이 PC(개발 노트북)에서 웹캠 + MoveNet 포즈 + ST3215 서보를 직접 묶어 사람을
따라가는 PTZ 추적을 처음으로 실동작시켰다. MCU를 거치지 않고 PC가 USB-TTL
어댑터(COM9)로 서보를 직접 구동하는 구조(`scripts/st3215_bus.py` 재사용).
사용자가 동작 결과에 만족("굉장히 맘에 든다")해서 이 상태를
`scripts/ptz_camera_track_v1.py`로 백업(byte-identical)했다.

신규 스크립트: `scripts/ptz_camera_track.py` (작업본) / `..._v1.py` (동결본).

## 배경

- 실행 환경 함정: 이 PC엔 파이썬이 둘(아나콘다 base = cv2 없음 / Python 3.14 =
  cv2·numpy·pyserial·ai-edge-litert 전부 있음). **반드시 Python 3.14로 실행**
  (`py -3.14 ...` 또는 전체경로). `ai-edge-litert`는 이번에 이 PC에 신규 설치.
- 카메라가 2대(index 0=내장 웹캠, index 1=짐벌 카메라) → `--camera 1` 사용.
- 안전: 서보 명령은 항상 소프트리밋(yaw 90~270=중앙±90 / pitch 150~210=중앙±30,
  tick 2047 캘리브레이션 기준) 안으로 3중 클램프. 안전속도(569 tick/s) 고정.
  기본은 dry-run(서보 미구동), `--drive` 줘야 실제 구동.

## 결과 — v1 확정 기능

- **목표점 폴백 체인**: 양쪽 무릎 다 보이면 두 무릎 중점 → 한쪽만/없으면 엉덩이
  중심 → 그래도 없으면 몸통(어깨+엉덩이). "한쪽 다리로 카메라 쏠림" 문제 해결.
  (`--target knee|hip|weighted`, `--one-knee`)
- **시작 시 항상 중앙(180/180) 이동 후 추적 시작** (torque는 현재 위치로 안전하게
  켠 뒤 중앙으로, 이동거리 비례 대기).
- **속도**: 추적 속도 기본 1/2(`track_scale=0.5`), 양 무릎 다 보이면 추가로 1/2
  → 총 1/4로 더 천천히(`both_knee_scale=0.5`).
- **섹터 프레이밍**: 화면 좌우 1/6·중앙 4/6·1/6. 무릎(양쪽 다 보이면 두 무릎 모두)이
  중앙 4/6 밴드 안이면 정지, 밖으로 나가야 팬. 미리보기에 밴드 경계 청록 세로선 표시.
  (`--sector-side`, 기본 1/6)
- **획득→잠금(도리도리 제거)**: 목표가 존 안에 N프레임 연속 머물면 LOCK(정지),(컴퓨터 기준 현재 10)
  재개는 히스테리시스로 충분히 벗어날 때만. EMA 스무딩으로 키포인트 지터 완화.
  (`--lock-frames`, `--reengage`, `--smooth`)
- 성능: 이 PC에서 ~29 FPS(데스크톱 CPU). yaw 부호는 기본(+1)이 맞음.

실행:
`py -3.14 scripts/ptz_camera_track.py --port COM9 --camera 1 --drive`

## 다음 단계

- **pitch 세로 프레이밍 튜닝**: 지금은 목표 y를 화면 정중앙(0.5)에 맞춰서, 무릎이
  화면 아래에 잡히면 카메라가 바닥 쪽으로 많이 틸트함. 스쿼트에선 무릎을 하단
  1/3(예: y=0.65~0.7)에 두는 게 자연스러움 → 목표 y 기준점 플래그화 검토.
- 이 로직을 본 파이프라인(`src/main.py`/`ptz_controller.py`)에 통합할지 검토
  (현재는 독립 테스트 스크립트). 단, 실기 UNO Q에선 서보를 Linux에서 직접 몰지
  MCU 경유할지 별도 결정 필요 — MCU 듀얼브레인 트랙은 사용자 지시로 잠정 보류 중.

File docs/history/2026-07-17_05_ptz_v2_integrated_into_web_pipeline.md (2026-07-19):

# 2026-07-17 — PTZ v2 추적 로직을 웹앱 본 파이프라인에 통합

## 시점

2026-07-17 (PTZ+스쿼트 v2
[2026-07-17_04](2026-07-17_04_ptz_squat_counting_v2.md) 이어서)

## 사건

독립 테스트 스크립트에만 있던 v2 추적 로직(무릎 중점 → 엉덩이 폴백, 중앙 4/6
섹터 밴드, 획득→잠금, 속도 감속)과 **서보 버스 직결 제어**를 본 파이프라인
(`src/ptz_controller.py`)에 이식했다. 이제 `src/main.py` 하나로 **웹앱(PWA) +
라이브 스트림 + 스쿼트/푸시업 카운팅 + PTZ 추적**이 한 프로세스에서 동시에 돈다.

작업 전 복원점: `backup/pre_web_integration/{src,scripts,docker}` (전체 복사본).

## 배경

- 기존 `ptz_controller.py`는 `/dev/ttyACM0`으로 `PAN +8` 텍스트를 MCU에 보내는
  구조였는데, UNO Q에는 MCU로 가는 raw serial 경로가 없어 **실기에서 작동 불가**
  였다(미검증 상태로 남아있던 잠재 버그). 서보 버스를 Linux가 직접 구동하는
  방식으로 교체하는 것이 통합의 핵심이었다.
- 웹앱에는 이미 스쿼트 카운팅이 있었으므로, v2가 실제로 더한 것은 **작동하는
  PTZ 추적 경로**다.

## 결과

**구조 변경**
- `scripts/st3215_bus.py` → **`src/st3215_bus.py`** 로 이동(런타임 모듈로 승격).
  벤치 스크립트 3종은 `src/`를 import 경로에 추가해 그대로 동작(회귀 확인).
- 무릎/엉덩이 중심 헬퍼(`knee_center_normalized`, `hip_center_normalized`)를
  `src/pose_utils.py` 공용 모듈로 승격 — 스크립트와 컨트롤러가 같은 코드를 씀.
- `src/ptz_controller.py` 전면 재작성: 버스 직결 + v2 추적 로직. **공개 API
  (`snapshot`/`set_auto_track`/`manual_pan`/`manual_tilt`/`manual_center`)를
  그대로 유지**해 `src/http_server.py`(웹 `/api/ptz`)는 **무변경**.
- `src/main.py`: `ptz.update(x_norm, y_norm, now_ms)` → **`ptz.update(kp, h, w, now_ms)`**
  (컨트롤러가 keypoint에서 목표점을 직접 산출). PTZ CLI 플래그를 새 파라미터로 교체.
- `docker/run.sh`·`Dockerfile`: 시리얼 디바이스를 `/dev/ttyACM0` → **`/dev/ttyUSB0`**
  (서보 버스 어댑터)로 변경.

**pitch 프레이밍 문제 발견·수정 (중요)**

두 파라미터의 의미:
- `pitch_target_y` = 무릎을 화면 **세로 어디에** 놓을지 목표 (0=맨위, 1=맨아래)
- `pitch_deadzone` = 목표에서 이만큼 벗어나기 전엔 **안 움직임** (화면 높이 대비)

| | 이전 | 변경 후 |
|---|---|---|
| `pitch_target_y` | 0.5 (화면 정중앙) | **0.62** (아래쪽 1/3 부근) |
| `pitch_deadzone` | 0.10 | **0.20** |
| 안 움직이는 세로 구간 | 40%~60% (폭 20%) | **42%~82% (폭 40%)** |

바꾼 이유 — 합성 keypoint 검증에서 실제로 재현된 두 문제:

1. **잠금이 영영 안 걸림.** 사람이 서 있으면 무릎은 자연스럽게 화면 아래쪽
   (y≈0.79)에 잡히는데, 목표가 0.5면 오차 0.29가 데드존 0.10을 항상 초과 →
   계속 "존 밖" 판정 → LOCK이 안 걸리고 카메라가 계속 아래로 틸트하려 듦.
   변경 후: 목표 0.62, 무릎 0.79 → 오차 0.17 < 데드존 0.20 → 정상 잠금.
2. **스쿼트마다 카메라가 끄덕임.** 스쿼트는 무릎이 상하로 움직이는 운동이라
   데드존이 좁으면 카메라가 매 rep을 따라 움직여 영상·카운팅 화면이 흔들림.
   데드존을 폭 40%로 넓혀 **운동 동작은 무시하고, 사람이 자리를 크게 옮겼을
   때만** 세로 프레이밍을 교정하도록 함.

재검증: 무릎 상하 진동(380↔300px) 시 **yaw/pitch 모두 전혀 안 움직이고 LOCK 유지**.

참고: 좌우(yaw)는 이 두 값과 무관 — yaw는 중앙 4/6 섹터 밴드로 따로 판정한다.
조절은 `--pitch-target-y` / `--pitch-deadzone` 플래그로 가능.

**검증**
- 합성 keypoint: 중앙 → LOCK(10프레임), 스쿼트 진동 → 무동작, 우측 밴드 밖 →
  잠금 해제 후 추적 재개, 미검출 → grace 후 LOST. 전부 정상.
- 실기 `main.py` 실행: `[ptz] 버스 연결 COM9 @ 1000000, 중앙(180/180) 정렬 후 시작`,
  이전 실행에서 틀어져 있던 서보(yaw 162.4)를 **시작 시 자동 중앙 정렬(→179.7)**.
  웹서버 `:8080` `/app`(뷰어·운영자) 기동, 카메라·추론·카운터 정상.
- 서보 미연결/전원 없음이면 **disabled 모드로 degrade**(추적 계산만, 웹 UI 정상).
  명령 카운터는 실제 전송된 것만 집계하도록 수정.

## 다음 단계

- 전신(발목까지)이 보이는 거리에서 실제 스쿼트로 카운팅 + 추적 동시 실측.
- yaw/pitch 부호는 `--yaw-sign`/`--pitch-sign`으로 실기 확인 필요(스크립트에서
  yaw는 기본 +1이 맞았음).
- UNO Q 실기 배포 시 `/dev/ttyUSB*` 실제 노드 확인 후 `SERIAL_DEV` 지정.

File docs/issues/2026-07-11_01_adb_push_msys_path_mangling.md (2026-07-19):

# Git Bash에서 `adb push`가 "성공" 메시지를 내고도 실제로는 파일을 안 옮김

## 증상

Git Bash(Bash 도구)에서 `adb push src/app_state.py /home/arduino/health_care_bot/src/app_state.py`
실행 시 `1 file pushed, 0 skipped ...` 성공 로그가 찍히지만, 바로 이어서
`adb: error: failed to copy '...' to 'C:/Program Files/Git/home/arduino/...':
remote secure_mkdirs failed: No such file or directory`도 함께 출력됨.
디바이스에서 `md5sum`/`wc -l`로 확인해보면 파일이 실제로 갱신되지 않았음
(구버전 그대로).

## 원인

`adb.exe`는 MSYS 빌드가 아닌 네이티브 Win32 실행파일인데, Git Bash(MSYS2)는
`/`로 시작하는 인자를 native 실행파일에 넘길 때 자동으로 Windows 경로로
변환한다. `adb push`의 두 번째 인자(디바이스 쪽 리모트 경로,
`/home/arduino/...`)가 `C:/Program Files/Git/home/arduino/...`로 잘못
변환되어 adb에 전달됨 — adb는 이걸 그대로 리모트 경로 문자열로 보내고,
디바이스(Linux)에서 그런 이름의 디렉토리를 만들려다 실패한 것.

## 해결

같은 명령을 PowerShell 도구로 재실행하면 경로 변환이 일어나지 않아 정상
동작. `md5sum`으로 디바이스 파일 해시를 재확인해 실제 반영 검증.

## 재발 방지

- **디바이스(리모트) 경로를 인자로 받는 adb 명령(`push`/`pull`/`shell`에
  절대경로 전달 등)은 Bash(Git Bash) 대신 PowerShell 도구를 사용한다.**
- Bash를 꼭 써야 하면 `MSYS_NO_PATHCONV=1` 환경변수로 우회 가능하다고
  알려져 있으나 이번엔 검증하지 않음 — PowerShell 사용이 확실한 방법.
- adb push 성공 로그만 보고 반영을 확신하지 말고, 중요한 파일은 push 후
  `md5sum`/`wc -l` 등으로 디바이스 쪽을 직접 재확인한다.

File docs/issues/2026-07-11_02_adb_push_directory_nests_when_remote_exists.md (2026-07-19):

# `adb push <local_dir> <remote_dir>`가 remote_dir이 이미 있으면 안에 중첩됨

## 증상

`web/dist`를 두 번째로 다시 push했는데 `6 files pushed` 성공 메시지가 떴지만,
디바이스의 `/home/arduino/health_care_bot/web/dist/assets/`에는 여전히 첫
push 때의 구버전 해시 파일(`index-C9fJj-zX.js` 등)만 있고 최신 빌드가
반영되지 않음.

## 원인

`adb push <local_dir> <remote_dir>`는 `remote_dir`이 **이미 존재하는
디렉토리**면 `local_dir`의 내용을 `remote_dir` 안에 바로 풀어놓는 게 아니라
`remote_dir/<local_dir 이름>/` 형태로 통째로 복사한다. 즉 이미
`/home/arduino/health_care_bot/web/dist`가 존재하는 상태에서
`adb push web/dist .../web/dist`를 다시 실행하면 실제로는
`.../web/dist/dist/`가 새로 생기고, 원래 있던 `.../web/dist/`는 그대로
구버전으로 남는다. `http_server.py`가 서빙하는 경로는 항상
`.../web/dist/`이므로 새 파일이 반영 안 된 것처럼 보임.

## 해결

```powershell
& $ADB shell "rm -rf /home/arduino/health_care_bot/web/dist"
& $ADB push web/dist /home/arduino/health_care_bot/web/dist
```

remote 경로를 먼저 지워서 "존재하지 않는 상태"로 만든 뒤 push하면 내용이
바로 그 경로에 풀린다.

## 재발 방지

- `web/dist`처럼 **매번 새 해시 파일명이 나오는 빌드 산출물 디렉토리**를
  다시 push할 땐 항상 `rm -rf <remote_dir>` 먼저 실행 후 push한다.
- push 후에는 성공 로그를 믿지 말고 `ls -la <remote_dir>/assets/`로 파일명
  해시가 로컬 최신 빌드와 일치하는지 직접 확인한다
  (`web/ARCHITECTURE.md`에는 없는, 순수 배포 절차 함정 — 관련:
  [`2026-07-11_01_adb_push_msys_path_mangling.md`](2026-07-11_01_adb_push_msys_path_mangling.md)).

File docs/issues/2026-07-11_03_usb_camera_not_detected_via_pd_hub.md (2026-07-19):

# PD 허브 경유 시 USB 카메라(+모든 USB 장치)가 전혀 열거되지 않음 (PC 재연결로 해결)

## 증상

UNO Q(`unoq-korea01`)의 USB-C 포트(보드에 있는 유일한 USB 포트, USB-A 등
별도 호스트 포트 없음)에 PD 허브를 연결 — 허브가 보드 전원(PD)과 카메라를
동시에 공급하는 구조. `docker run`으로 `main.py` 실행 시
`ERROR: cannot open camera /dev/video0` (`/dev/video0`·`/dev/video1`은
Qualcomm Venus 코덱 노드, 실제 UVC 카메라 아님). `lsusb`에 root hub 2개만
보이고 외부 허브·카메라가 전혀 안 잡힘. 카메라 대신 단순 USB 저장장치를
같은 허브에 꽂아도 마찬가지로 전혀 인식 안 됨 — 카메라 특정 문제가 아님.

## 원인

**허브가 PD로 전원을 내보내는 것과 USB 데이터 허브 역할을 동시에 수행하지
못함.** 같은 허브를 일반 PC에 "PD 없이"(PC가 자체 전원으로 동작, 허브는
순수 데이터 허브 역할만) 연결하면 데이터 인식이 정상 동작하는 것을 확인 —
즉 허브의 데이터 라인 자체는 멀쩡하다. 문제는 UNO Q처럼 **허브가 다운스트림
호스트(보드)에 PD로 전원을 공급해야 하는 상황에서만** 재현됨. 허브
칩셋/펌웨어가 "PD power delivery 협상 활성" 상태에서 USB data mux를
제대로 유지하지 못하는(또는 아예 꺼버리는) 것으로 보인다.

이 결과로 "PD 전원 공급 + 데이터 허브"를 표방하는 제품이라면 **핵심 광고
기능(동시 지원)이 실제로 안 되는 것**이 확인된 셈 — 환불/교환 사유로
타당함.

### 확인 과정에서 배제한 가설들 (기록용)

- ~~허브/케이블에 데이터 라인이 아예 없음(충전 전용)~~ — PC에 PD 없이
  연결했을 때 데이터가 정상 동작하는 것으로 기각. 데이터 라인 자체는 있음.
- ~~보드가 host VBUS를 안 내보내는 문제~~ — `power_role: [sink]` 확인 후
  기각. Sink 역할이면 VBUS는 허브가 공급하는 게 정상.
- ~~보드가 Sink(전원)+Host(데이터) 동시 지원 안 됨~~ — `/sys/class/typec/port0/data_role`이
  이미 `[host] device`로 잡혀 있어 role 조합 자체는 문제 없음. 보드 쪽은
  정상.
- `dmesg`의 `l5: disabling` / `usb_vbus: disabling` (boot ~34s) — WiFi 연결
  직후 타이밍인 걸 보면 카메라/허브와 무관하게 부팅 후 아무도 안 쓰는
  레귤레이터를 커널이 정리하는 정상 동작으로 재해석. red herring이었음.

## 해결

**허브를 PC에 한 번 연결했다 뺀 뒤 다시 UNO Q에 꽂으면 초기화되어 카메라가
정상 인식됨.** 하드웨어 교체 없이 이 재연결 트릭으로 해결.

- 허브 교체는 필요 없어짐 — 데이터 라인 자체는 처음부터 멀쩡했고
  (위 "확인 과정에서 배제한 가설들" 참고), PD 활성 상태에서 걸리던
  negotiation이 PC 재연결로 리셋되는 것으로 보임.
- **다만 재발 가능성 있음** — 근본적으로 왜 이 상태에 빠지는지(펌웨어
  버그 vs 특정 negotiation 타이밍)까지는 확인 못 함. USB 재연결/재부팅마다
  카메라가 다시 안 잡히면 같은 방법(허브를 PC에 잠깐 연결 후 재초기화 →
  UNO Q에 재연결)으로 대응.
- `docs/history/2026-07-11_05_pd_hub_confirmed_defective_refund.md`에
  최종 결과 기록.

## 재발 방지

- "PD 전원 + USB 데이터"를 한 허브로 동시에 쓰는 구성을 짤 땐, 구매 전에
  "simultaneous power delivery and data" 또는 이에 준하는 문구가 제품
  스펙에 명시돼 있는지 확인할 것.
- 카메라가 다시 안 잡히면 우선 **허브를 PC에 재연결해 초기화**해보고,
  그래도 안 되면 아래 순서로 SSH만으로 좁힐 수 있음: (1) `lsusb`/`dmesg | grep usb`
  로 완전 무반응인지 확인 → (2) `/sys/class/typec/port0/{power_role,data_role}`
  로 role 협상 자체는 됐는지 확인(보드 쪽 문제 배제) → (3) 카메라 대신
  단순 USB 저장장치로 교차검증(카메라 특정 문제 배제) → (4) 같은 허브를
  PD 없이 일반 PC에 연결해 데이터 라인 자체 결함인지 구분.

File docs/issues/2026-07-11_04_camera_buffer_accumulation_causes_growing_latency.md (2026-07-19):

# 카메라 버퍼 누적으로 체감 지연이 계속 커짐 (스무스하지만 지연 김)

## 증상

라이브 스트림 영상이 프레임 단위로는 매끄럽게 재생되는데, 실시간보다
체감상 훨씬 긴 지연이 느껴짐. `/stats.json`의 `loop_ms`(당시 ~90ms,
`fps` ~10.8)만 보면 그 정도 지연은 설명이 안 될 만큼 체감 지연이 컸음 —
즉 `loop_ms`가 측정하는 구간과 실제 지연 발생 구간이 달랐다는 신호.

## 원인

카메라(USB UVC)는 CPU 처리 상태와 무관하게 자체 속도로 계속 프레임을
캡처한다(예: ~33ms/frame ≈ 30fps). 반면 추론 루프(MoveNet 추론 + pose
draw + JPEG 인코딩)는 한 사이클에 ~90ms(≈11fps) 걸려 캡처 속도를 못
따라간다.

기존 `main.py`는 이 느린 처리 루프 **안에서 직접** `cap.read()`를
호출했다. `cap.set(cv2.CAP_PROP_BUFFERSIZE, 1)`로 드라이버 버퍼를 1로
줄이려 시도했지만, 이 옵션은 V4L2/UVC 드라이버에 따라 **무시되는 경우가
흔해** 실질적인 안전장치가 되지 못했다. 그 결과:

1. 카메라는 계속 프레임을 만들어 드라이버 내부 버퍼(큐)에 쌓는다.
2. 처리 루프가 `cap.read()`를 부르면 그 큐에서 **가장 오래된(FIFO)**
   프레임을 반환한다.
3. 처리(캡처)가 느리니 큐는 계속 다시 채워지고, 매번 꺼내는 프레임은
   점점 더 "예전에 찍힌" 것이 된다 — 지연이 누적됨.
4. 각 프레임 자체는 일정한 간격으로 처리·표시되므로 재생은 매끄러워
   보이지만, 그 매끄러움이 실시간보다 계속 뒤처진 채로 유지되는 것일
   뿐이다.

## 해결

`src/main.py`에 `FrameGrabber` 클래스 추가 — 카메라 읽기를 별도 스레드로
완전히 분리해 **큐가 아니라 "최신 프레임 1장 덮어쓰기"** 방식으로
바꿨다. 백그라운드 스레드가 계속 `cap.read()`를 호출해 최신 프레임과
`frame_id`를 갱신하고, 메인 추론 루프는 매 반복마다 그 시점의 최신
프레임만 가져다 쓴다(같은 `frame_id`면 처리 안 하고 짧게 대기). 이러면
처리 루프가 아무리 느려도 처리 대상 프레임의 "나이"가 캡처 스레드
주기 이상으로는 절대 누적되지 않는다.

배포 후 실측: 지연은 체감상 크게 개선("실시간성이 있다")됐고,
`fps`(처리량)는 10.8 ±4로 수정 전후 동일 — 이는 회귀가 아니라
FrameGrabber가 **지연만 고치고 처리량은 원래 그대로 두는 게 의도**였기
때문. 상세: [`docs/history/2026-07-15_01_framegrabber_verified_latency_fixed_fps_unchanged.md`](../history/2026-07-15_01_framegrabber_verified_latency_fixed_fps_unchanged.md),
설계 근거: `web/ARCHITECTURE.md` §8.

## 재발 방지

- **`cv2.CAP_PROP_BUFFERSIZE`를 신뢰하지 말 것** — 설정해도 드라이버가
  무시할 수 있다. 카메라 캡처 속도가 처리 속도보다 빠를 가능성이 있는
  파이프라인(추론/인코딩이 무거운 경우 전부 해당)에서는 처음부터
  캡처를 별도 스레드로 분리하고 "최신 프레임만 유지" 패턴을 기본값으로
  쓴다.
- "재생이 매끄럽다"는 "지연이 없다"의 증거가 아니다 — 큐 기반 파이프라인은
  얼마든지 매끄러우면서 지연이 크거나 계속 커질 수 있다. 지연을 의심할
  땐 `loop_ms`(처리 시간)와 체감 지연을 분리해서 봐야 하고, `loop_ms`로
  설명 안 되는 체감 지연이 있으면 버퍼 누적을 의심한다.
- FPS(처리량)와 지연(latency)은 서로 다른 지표다 — 지연을 고쳤다고
  FPS가 오르는 게 아니고, FPS를 올리려면 추론/인코딩 자체를 빠르게
  만드는 별도 작업이 필요하다.

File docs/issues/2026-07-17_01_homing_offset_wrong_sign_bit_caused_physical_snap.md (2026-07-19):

# ST3215 Homing_Offset 잘못된 부호비트로 실제 회전 → 출력물 파손

## 증상

짐벌 조립 상태에서 "지금 물리 위치를 논리 중앙으로 캘리브레이션"하려고
서보 EEPROM의 Position Correction(Homing_Offset, addr 31~32) 레지스터에
음수 오프셋을 썼는데, 서보가 갑자기 실제로 크게 회전해버렸고 그 과정에서
3D 프린트 출력물(짐벌 하우징)이 부러졌다. Present_Position 계산도
매번 다른 이상한 값이 나와 예측이 전혀 안 됐다.

## 원인

두 가지가 겹쳤다.

1. **부호비트 위치를 잘못 가정함.** Present_Position 레지스터는
   bit15가 부호비트(매그니튜드 15bit)인데, **Homing_Offset 레지스터는
   STS3215에서 bit11이 부호비트**(매그니튜드 최대 ±2047)다. 이 스크립트는
   처음에 두 레지스터 모두 bit15로 인코딩했다 — 양수 값(예: +100)은
   부호비트가 애초에 0이라 우연히 두 방식이 같은 값을 내서 정상 동작하는
   것처럼 보였지만, **음수 값을 쓰면 완전히 다른(부호비트 위치가 어긋난)
   raw 값**이 저장되어 서보가 엉뚱한 오프셋으로 해석했다.
2. **torque가 켜진 상태에서 오프셋을 바꿈.** Present_Position =
   Actual_Position - Homing_Offset 관계상, 오프셋을 바꾸면 Present_Position이
   순간적으로 크게 달라진 것처럼 보인다. 서보 내부 위치 제어 루프가 켜져
   있으면(Torque_Enable=1), 이 "달라진" Present_Position과 이전에 남아있던
   Goal_Position(직전 수동 `move` 테스트에서 보낸 값) 사이의 오차를 실제
   회전으로 메우려고 하면서 큰 폭의 예상치 못한 회전이 발생했다. 이게
   출력물 파손의 직접 원인.

정확한 레지스터 주소/공식/부호비트는 STS3215와 동일 모터를 쓰는
LeRobot(HuggingFace SO-101/SO-100 로봇팔)의 공식 오픈소스 구현으로 확인:
- 주소: [`feetech/tables.py`](https://github.com/huggingface/lerobot/blob/main/src/lerobot/motors/feetech/tables.py) — `Homing_Offset: (31, 2)`
- 공식: [`feetech.py`](https://github.com/huggingface/lerobot/blob/main/src/lerobot/motors/feetech/feetech.py) `_get_half_turn_homings` 주석 — `Present_Position = Actual_Position - Homing_Offset`
- 부호비트: [`feetech/tables.py`](https://github.com/huggingface/lerobot/blob/main/src/lerobot/motors/feetech/tables.py) `MODEL_ENCODING_TABLE` — `Homing_Offset: 11`, `Present_Position: 15`
- 인코딩 방식: [`encoding_utils.py`](https://github.com/huggingface/lerobot/blob/main/src/lerobot/motors/encoding_utils.py) `encode_sign_magnitude`/`decode_sign_magnitude`

## 해결

`scripts/test_st3215_serial.py` 수정:
- `_encode_sign_magnitude(value, sign_bit_index)` / `_decode_sign_magnitude(raw, sign_bit_index)`로
  부호비트 위치를 파라미터화. `Present_Position`은 15, `Homing_Offset`은 11로 분리.
- `calibrate_center()`가 실행 전 **Torque_Enable을 직접 읽어서 0이 아니면
  즉시 예외를 던지고 중단**하도록 안전장치 추가 — 앞으로 이 사고가 재발할
  방법 자체를 차단.
- 캘리브레이션 목표를 LeRobot과 동일한 컨벤션(`Homing_Offset = Actual_Position - 2047`,
  즉 tick 0~4095의 정중앙)으로 통일.

수정 후 torque off 상태에서 재실행해 두 서보 모두 물리적 이동 없이
정확히 tick 2047로 캘리브레이션 완료 확인(상세는
[`docs/history/2026-07-17_01_yaw_pitch_center_calibration_completed.md`](../history/2026-07-17_01_yaw_pitch_center_calibration_completed.md)).

## 재발 방지

- **STS3215 계열 레지스터는 신호(sign) 비트 위치가 레지스터마다 다르다** —
  Present_Position(15)과 Homing_Offset(11)을 혼동하지 말 것. 새 레지스터를
  다룰 땐 매번 LeRobot의 `feetech/tables.py`(`MODEL_ENCODING_TABLE`)로
  대조 확인한다. 이 프로젝트 자체 문서 없이 register map을 추측하지 않는다.
- **Torque_Enable=1인 상태에서 Homing_Offset(또는 다른 위치 관련 EEPROM
  레지스터)을 바꾸지 않는다** — 반드시 먼저 torque off, 캘리브레이션 완료
  후 torque를 다시 켜기 전에 Goal_Position을 새 Present_Position에 맞춰
  동기화한다.
- 작은 테스트 값(예: +100)으로 먼저 검증하고 확대 적용하는 습관이 이번에
  진짜 원인(부호비트 위치)을 찾는 데 결정적이었다 — 앞으로도 레지스터
  실험은 작은 값 → 검증 → 확대 순서로.

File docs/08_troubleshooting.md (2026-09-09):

# 트러블슈팅 · 함정 색인

본 문서는 **증상에서 원인으로 가는 길**을 모아둔 색인입니다. 각 항목은 요약만 담고, 상세
경위는 `issues/`의 해당 파일로 넘깁니다. 같은 함정을 두 번 밟지 않는 것이 목적입니다.

## 0. 증상에서 시작하기

| 증상 | 가장 흔한 원인 | 절 |
|---|---|---|
| 컨테이너가 뜨자마자 죽는다 | 카메라 노드 오지정 / argparse 인자 불일치 | §1 |
| 폰만 접속이 안 된다 | 폰 랜덤 MAC | §2 |
| 카메라·서보가 **둘 다** 안 잡힌다 | 허브 전원(호스트 VBUS) | §3 |
| PTZ만 안 움직인다 | 시리얼 노드 미검출 → disabled | §4 |
| 서보 ID 전부 무응답 | 서보 외부전원 없음 | §4 |
| 영상이 매끄러운데 지연이 크다 | 카메라 버퍼 누적 | §5 |
| 코드를 밀었는데 반영이 안 된다 | adb push 중첩 / Git Bash 경로 변환 | §6 |
| 웹을 고쳤는데 안 바뀐다 | 고친 파일이 `web/app/index.html`이 맞는지 (배포본은 여기 하나) | §6 |
| `mock_serve.py`가 안 뜬다 | 2026-09-09에 고쳐졌다. 그 전 버전이면 `PushupCounter` import 에러 | [`07`](07_runbook.md) §7 |
| 콘솔에서 `UnicodeEncodeError` | cp949 콘솔 + em-dash·이모지 | §7 |
| 경비 모드 "직접 촬영"이 씹힌다 | (해결됨) 자동 감지와 쿨다운 공유였음 | §8 |
| 디스크가 찬다 | `captures/`에 사진이 계속 쌓임 — 자동 정리 없음 | §8 |

## 1. 기동 실패 / 즉시 종료

| 함정 | 요약 |
|---|---|
| **카메라 노드 오지정** | `Qualcomm Venus`(코덱) 노드를 카메라로 열려다 실패 → `cannot open camera`로 즉시 종료. 노드 번호는 부팅마다 바뀐다. 이름으로 식별할 것 → [`issues/2026-07-19_01`](issues/2026-07-19_01_device_node_names_are_not_stable.md) |
| **argparse choices ↔ 하드코딩 인자 불일치** | `--mode`에서 `auto`를 없앴는데 `run.sh`가 `--mode auto`를 넘겨 컨테이너가 즉시 종료됐다(`invalid choice`). run.sh는 고쳤지만 **`docker/Dockerfile`의 `CMD`에 아직 `--mode auto`가 남아 있다** → `run.sh` 없이 `docker run`하면 같은 증상 |
| **`--rm`이라 로그가 안 남는다** | 죽은 컨테이너는 `docker logs`에 없다. `bash docker/run.sh > /tmp/hcb_run.log 2>&1`로 캡처 |
| 모델 파일 없음 | `ERROR: model not found` → `bash scripts/copy_model.sh` |

## 2. 네트워크 · 접속

**크롬 에러 메시지로 원인을 먼저 가른다:**

| 에러 | 의미 | 원인 방향 |
|---|---|---|
| **`ERR_ADDRESS_UNREACHABLE`** | 대상 IP로 가는 **경로 없음** | 폰이 그 서브넷 밖 — 랜덤 MAC / 셀룰러 폴백 / 다른 SSID |
| `ERR_CONNECTION_TIMED_OUT` | 경로는 있는데 응답 없음 | AP 클라이언트 격리 / 방화벽 |
| `ERR_CONNECTION_REFUSED` | 닿았는데 포트 닫힘 | 서버 미기동 / 포트 오류 |

`ADDRESS_UNREACHABLE`는 **서버·네트워크 문제가 아니라 폰이 그 LAN에 실제로 안 붙어 있다는
신호**다. 실제로 이 증상에서 웹 버전 롤백까지 시도했으나 원인은 폰이었다.

**폰 쪽 진단 순서**: ① 모바일 데이터 OFF(로봇 Wi-Fi에 인터넷이 없으면 LTE로 새어나간다) →
② 다른 폰과 **정확히 같은 SSID**(…5G/guest/중계기 아님) → ③ 폰 IP가 `192.168.0.x`인지 →
④ Wi-Fi 잊기·재접속("인터넷 없음, 연결 유지?" → 유지) → ⑤ **랜덤 MAC OFF** →
⑥ VPN/사설DNS OFF.

> **데모 당일**: 참석자 폰도 같은 함정에 걸릴 수 있다. 접속 안 되는 폰은 "그 네트워크에서
> 랜덤 MAC 끄기"를 먼저 안내할 것.
> 상세: [`issues/2026-07-26_01`](issues/2026-07-26_01_mobile_web_access_fails_random_mac.md)

## 3. USB · 장치 인식

| 함정 | 요약 |
|---|---|
| **호스트 VBUS가 꺼져 있다** | UNO Q는 `usb_vbus=disabled`(단 `usb_role=host`)라 **버스파워 허브/장치는 enumeration 자체가 안 된다**(`lsusb`에 루트 허브만). **셀프파워 허브 필수.** 카메라·서보가 *둘 다* 안 잡히면 개별 장치가 아니라 허브 전원부터 의심 |
| **PD 허브 데이터 라인 미인식** | PD 전원 공급 중에는 데이터 허브 역할을 못 하던 개체. **허브를 PC에 한 번 꽂았다 빼면 초기화되어** 정상 인식 → [`issues/2026-07-11_03`](issues/2026-07-11_03_usb_camera_not_detected_via_pd_hub.md) |
| 노드 번호 변동 | `/dev/videoN`·`ttyACM/ttyUSB`가 부팅마다 바뀐다 → [`issues/2026-07-19_01`](issues/2026-07-19_01_device_node_names_are_not_stable.md) |

**진단 명령**:

```bash
for r in /sys/class/regulator/*/; do echo "$(cat $r/name)=$(cat $r/state)"; done | grep -i usb
cat /sys/class/usb_role/*/role
lsusb                                    # 외장 허브가 보이는지
dmesg | grep -iE "vbus|cdc_acm|new .*USB device"
```

정상이면 `lsusb`에 카메라 + CH343 시리얼 + 허브가 보인다. **허브 제조사는 개체마다 다르니
이름을 조건으로 외우지 말고 "세 개가 다 보이는가"만 확인한다.** 2026-09-08 실측:

```
Bus 001 Device 002: ID 05e3:0608 Genesys Logic, Inc. Hub
Bus 001 Device 003: ID 05a3:9230 ARC International Camera
Bus 001 Device 004: ID 1a86:55d3 QinHeng Electronics USB Single Serial
```

## 4. 서보 · PTZ

| 함정 | 요약 |
|---|---|
| **서보 외부전원 없음** | 전원(6~12.6V)이 없으면 포트는 정상으로 열리는데 **ID 전부 무응답**. COM 포트/ID 문제로 오해하기 쉽다 → **어댑터 배럴잭 먼저** |
| **PTZ disabled가 조용하다** | 시리얼 노드를 못 찾으면 한 줄 경고 뒤 정상 실행이 계속된다. 기동 로그의 `serial :` 줄부터 볼 것 |
| **torque ON 상태 EEPROM 변경 금지** | offset을 torque 켠 채 바꾸면 옛 `Goal_Position`으로 실제 회전 → **3D 출력물 파손 이력.** `calibrate` 명령을 쓸 것 → [`issues/2026-07-17_01`](issues/2026-07-17_01_homing_offset_wrong_sign_bit_caused_physical_snap.md) |
| **부호비트 위치가 레지스터마다 다르다** | `Homing_Offset`=bit11, `Present_Position`=bit15. 양수는 우연히 같아 정상처럼 보이고 **음수에서 터진다** |
| **서보 ID 변경은 즉시 반영** | "전원 재투입 필요"라는 일반 SDK 문구와 다르다. `set-id` 실패 로그가 떠도 새 ID로 `ping`해 확인 → [`issues/2026-07-16_01`](issues/2026-07-16_01_servo_id_change_takes_effect_immediately.md) |
| 공장 출하 ID 충돌 | ST3215는 전부 ID=1이다. **체인 연결 전에 낱개로** 1/2를 나눠 기록 |
| 목표각 ≠ 실제각 | 런타임에 서보 위치를 읽지 않으므로 어긋나도 감지 못 한다. 의심되면 `test_st3215_serial.py --id N read` |

절차: [`06_hardware_calibration.md`](06_hardware_calibration.md)

## 5. 카메라 · 영상

| 함정 | 요약 |
|---|---|
| **`cv2.CAP_PROP_BUFFERSIZE`를 믿지 말 것** | V4L2/UVC 드라이버가 무시하는 경우가 흔하다. 캡처가 처리보다 빠르면 버퍼에 프레임이 쌓여 **지연이 계속 커진다**. `FrameGrabber`(최신 1장만 유지)로 해결됨 → [`issues/2026-07-11_04`](issues/2026-07-11_04_camera_buffer_accumulation_causes_growing_latency.md) |
| "매끄럽다 ≠ 지연 없다" | 큐 기반 파이프라인은 매끄러우면서 지연이 계속 커질 수 있다. `loop_ms`로 설명 안 되는 체감 지연이면 버퍼 누적을 의심 |
| FPS와 지연은 다른 지표 | 지연을 고쳤다고 FPS가 오르지 않는다. FPS는 추론/인코딩 자체를 빠르게 해야 오른다 → [`09`](09_performance_roadmap.md) |
| 카메라 레이트 캡이 안 먹는다 | 15fps 캡을 시도해도 카메라가 무시하고 30.5를 유지한 사례 있음 |
| 스트림 첫 프레임이 늦다 | `--idle-skip-draw`로 실행 중이고 뷰어가 0명이었으면 정상 |

## 6. 배포 · 반영 안 됨

| 함정 | 요약 |
|---|---|
| **Git Bash로 adb push** | MSYS가 리모트 경로를 Windows 경로로 변환해 **조용히 실패**한다. **PowerShell로** → [`issues/2026-07-11_01`](issues/2026-07-11_01_adb_push_msys_path_mangling.md) |
| **디렉토리 push 전 remote `rm -rf`** | remote 경로가 이미 있으면 `src/src/`·`dist/dist/`로 중첩된다. 구버전이 서빙돼 "반영 안 됨"으로 보임 → [`issues/2026-07-11_02`](issues/2026-07-11_02_adb_push_directory_nests_when_remote_exists.md) |
| push 로그를 믿지 말 것 | `md5sum`으로 대조 |
| ~~**`npm run build`가 Fluid를 덮는다**~~ | **해소(2026-09-09)** — 배포본이 `web/app/`으로 분리됐고 서버가 `web/app` → `web/dist` 순으로 찾는다 → [`05`](05_web_ui_fluid.md) §9-1 |
| **SSH 세션 안에서 PC 명령** | PowerShell 문법을 붙여넣으면 bash `syntax error`. 더 나쁜 건 `ssh`를 또 실행해 **자기 자신에게 재접속**하는 것. 프롬프트를 먼저 볼 것 |
| **PowerShell 파이프로 `authorized_keys` 등록 금지** | PS 5.1이 CRLF/BOM을 섞어 키가 조용히 깨진다. 디바이스 셸에서 `echo '<pubkey>' >> ~/.ssh/authorized_keys` |
| `pkill -f "http.server ..."` | 패턴이 **자기 셸까지 매칭**해 SSH 세션이 끊긴다(exit 255). PID로 kill하거나 bracket 트릭 |

## 7. 개발 환경 (PC · 콘솔)

| 함정 | 요약 |
|---|---|
| **`py -3.14`를 쓸 것** | 아나콘다 `base`엔 `cv2`가 없다. `ModuleNotFoundError: cv2`가 나면 인터프리터를 잘못 잡은 것 |
| **cp949 콘솔 유니코드 크래시** | em-dash(`—`)·`⚠` 등이 Windows 콘솔에서 `UnicodeEncodeError`를 낸다. **파이썬 코드/주석에 쓰지 말 것**(마크다운 문서에는 무관) |
| 카메라 인덱스 변동 | USB 재연결마다 뒤바뀐다. 각 인덱스에서 한 장 캡처해 확인 |
| PC vs 실기 관성 차이 | 관성 지속만 프레임 수 기준이라 PC(29 FPS)에서 2.6배 짧게 보인다 → [`03`](03_algorithm_ptz_tracking.md) §12 |
| 한글 웹폰트 서브셋 | 코드포인트 순으로 쪼개면 효과가 없다(빈도와 무상관). 우선 조각 방식으로 해결됨 → [`issues/2026-07-20_01`](issues/2026-07-20_01_unicode_range_chunking_by_codepoint_is_useless.md) |

## 8. `issues/` 전체 색인

| 파일 | 주제 |
|---|---|
| [`2026-07-11_01`](issues/2026-07-11_01_adb_push_msys_path_mangling.md) | Git Bash adb push 경로 변환 |
| [`2026-07-11_02`](issues/2026-07-11_02_adb_push_directory_nests_when_remote_exists.md) | adb push 디렉토리 중첩 |
| [`2026-07-11_03`](issues/2026-07-11_03_usb_camera_not_detected_via_pd_hub.md) | PD 허브 카메라 미인식 |
| [`2026-07-11_04`](issues/2026-07-11_04_camera_buffer_accumulation_causes_growing_latency.md) | 카메라 버퍼 누적 지연 |
| [`2026-07-16_01`](issues/2026-07-16_01_servo_id_change_takes_effect_immediately.md) | 서보 ID 즉시 반영 |
| [`2026-07-17_01`](issues/2026-07-17_01_homing_offset_wrong_sign_bit_caused_physical_snap.md) | Homing_Offset 부호비트 → 출력물 파손 |
| [`2026-07-19_01`](issues/2026-07-19_01_device_node_names_are_not_stable.md) | 디바이스 노드 번호 불안정 |
| [`2026-07-20_01`](issues/2026-07-20_01_unicode_range_chunking_by_codepoint_is_useless.md) | 한글 폰트 코드포인트 분할 무용 |
| [`2026-07-26_01`](issues/2026-07-26_01_mobile_web_access_fails_random_mac.md) | 폰 랜덤 MAC 접속 실패 |

새 함정을 밟았으면 **한 사건 한 파일**로 `issues/`에 추가하고(증상 → 원인 → 해결 → 재발
방지), 본 문서 §0·§8에 한 줄 추가한다.

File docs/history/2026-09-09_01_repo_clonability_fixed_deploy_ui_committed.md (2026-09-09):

# 2026-09-09 리포 클론 가능성 복구 — 배포 UI 커밋 · Dockerfile CMD · 문서 정합

> 앞선 세션([`2026-09-08_01`](2026-09-08_01_docs_synced_to_runtime_verified_on_device.md))에서
> 문서를 실기 런타임에 맞췄는데, 그때 **"리포 안"만 맞췄고 "리포 밖"이 남아 있었다.**
> 이 문서는 그 나머지를 정리한 기록이다.

---

## 1. 한 줄 요약

**처음 보는 사람이 clone해서 `/app`까지 도달하지 못하는 상태**였다. 배포 UI가 gitignore된
`web/dist/`에만 있었기 때문이다. 배포본을 커밋되는 `web/app/`으로 옮기고 서버가
`web/app` → `web/dist` 순으로 찾게 했다. 덤으로 `docker run` 직접 호출이 즉사하던
Dockerfile CMD, 실행 불가였던 `mock_serve.py`, 실제와 어긋난 README 폴더 트리를 고쳤다.

---

## 2. 무엇이 문제였나

### 2-1. 배포 UI가 리포에 아예 없었다 (가장 큰 문제)

README §4 · [`00`](../00_project_blueprint.md) · [`05`](../05_web_ui_fluid.md) §9가
`web/dist/index.html`을 **"현재 `/app`으로 서빙되는 확정 UI, 유일한 최신본"** 이라고
못박고 있었는데, `web/.gitignore`의 `dist` 규칙 때문에 그 파일은 **커밋 이력에 한 번도
없었다**(`git log -- web/dist` → 없음).

결과:

- clone하면 `/app`이 `503 {"error": "web_not_built"}`.
- 안내대로 `npm run build`를 하면 `web/src`의 React 시안이 나온다 — 문서가 말하는
  "Fluid"가 아니다.
- README §8이 "`npm run build`하면 Fluid가 덮인다"고 경고하는데, **클론 환경엔 덮일
  Fluid 자체가 없었다.** 문서가 서술하는 시대와 코드의 시대가 달랐다.

### 2-2. Dockerfile CMD가 죽는 인자를 들고 있었다

`docker/Dockerfile`의 `CMD`가 `--mode auto`인데 argparse choices는
`squat/overhead/lateral/guard`([`src/main.py:154`](../../src/main.py))다.
`docker run`을 직접 부르면 **exit 2로 즉사**한다. `docker/run.sh`가 `--mode squat`로
덮어써서 가려져 있었을 뿐이다. `--rm`이라 `docker logs`에도 안 남는다.

README §8에 "argparse ↔ run.sh 동기화"라는 함정 항목이 **이미 있었는데도** Dockerfile은
2026-07-26 pushup 제거 때 같이 고쳐지지 않았다.

### 2-3. `scripts/mock_serve.py`가 실행 불가였다

pushup 제거(2026-07-26) 이후 갱신되지 않아 세 군데가 죽어 있었다:

- `from exercise_counter import ... PushupCounter` → **ImportError** (import 단계에서 즉사)
- `init_app(..., pushup_c=...)` → TypeError (시그니처가 `overhead_c`/`lateral_c`로 바뀜)
- `app_state.set_mode("auto")` → `{"ok": false, "error": "invalid_mode"}`

README §4에는 정상 도구로 올라가 있었다.

### 2-4. 문서 ↔ 실제 불일치

| README 기재 | 실제 |
|---|---|
| `stl/` | `3d_model/` (하위 `3mf`·`source`·`stl`·`validation`·`preview`) |
| 복원점 3개 | `backup/` 5개 |
| 모델은 git 미포함 (§10, §3.4) | `models/movenet_thunder_int8.tflite` 7.1 MB **커밋되어 있음** |
| (누락) | `APP_PLAN.md`, `health_care_bot_mvp_screen_plan.md`, `app_reference.png`, `APP_GUIDE.md` |
| §10 제목 "모델 / 라이센스" | 라이센스 문장 없음 · LICENSE 파일 없음 |

`web/README.md`는 손대지 않은 Vite 보일러플레이트 그대로였다.

---

## 3. 어떻게 고쳤나

### 3-1. 배포본을 `web/app/`으로 (핵심)

`web/dist/index.html`(49,022 B)은 **완전 자체포함**이다 — 외부 JS·CSS·`@font-face`가
하나도 없고 시스템 폰트만 쓴다(확인함). 그래서 파일 하나만 옮기면 끝난다.

```
web/app/index.html      ← 커밋. 배포본. 여기를 직접 고친다
web/dist/               ← 그대로 gitignore. React 시안 빌드 산출물일 뿐
```

`src/http_server.py`의 `_WEB_DIST` 단일 경로를 `_WEB_DIRS` 튜플로 바꾸고,
`_resolve_static()`이 **`web/app` → `web/dist` 순으로** 찾도록 했다.

이 순서가 핵심이다:

- **clone 직후 빌드 없이 `/app`이 뜬다** — 503 소멸.
- **`npm run build`가 배포 UI를 못 덮는다** — dist를 덮어도 `/app`은 `web/app`을 본다.
  README §8 · [`05`](../05_web_ui_fluid.md) §9-1의 함정이 코드 레벨에서 사라졌다.
- **아직 옮기지 않은 디바이스도 그대로 동작한다** — `web/app`이 없으면 기존
  `web/dist/index.html`로 폴백되므로, 배포 전에도 화면이 바뀌지 않는다.
- `/app/assets/*`(React 시안 자산)는 계속 `web/dist`에서 나온다.

경로 탈출 차단(`resolve()` + `relative_to()` → 403)은 디렉터리마다 각각 적용된다.

### 3-2. Dockerfile CMD

`--mode auto` → `--mode squat` (run.sh가 넘기는 값과 동일). 헤더 주석의 `pushup`도
`squat / overhead / lateral / guard`로 갱신.

### 3-3. 운영자 PIN을 환경변수로

PIN이 `src/app_state.py`에 하드코딩(`1234`)되어 있어 README의 "시연 전 교체 권장"을
따르려면 **코드를 고치는 수밖에 없었다.** 환경변수 오버라이드를 넣었다:

```python
_DEFAULT_OPERATOR_PIN = "1234"
_operator_pin = os.environ.get("HCB_OPERATOR_PIN", "").strip() or _DEFAULT_OPERATOR_PIN
```

`docker/run.sh`가 `HCB_OPERATOR_PIN`이 설정된 경우에만 `-e`로 전달한다:

```bash
HCB_OPERATOR_PIN=8317 bash docker/run.sh
```

**기본값은 그대로 `1234`** 이므로 지금까지의 동작은 변하지 않는다.
(이건 인증이 아니라 오조작 방지다 — [`02`](../02_http_api_and_stats.md) §6 그대로.)

> **푸시 직전 리뷰에서 잡은 것** — 서버만 고쳐서는 반쪽이었다. 배포 UI가
> `post("/api/control/claim",{pin:"1234"})`로 **PIN을 하드코딩**하고 PIN 입력
> 화면이 아예 없어서(§4 "누구나 조종"), `HCB_OPERATOR_PIN`을 실제로 바꾸면
> **PTZ·모드전환·촬영 버튼이 전부 조용히 먹통**이 된다. README에 "시연 전 교체
> 권장"이라고 써 놓고 그대로 하면 데모가 깨지는 상태였다.
>
> `ensureControl()`이 `invalid_pin`을 받았을 때**만** `prompt()`로 한 번 묻고
> `localStorage`(`hcb.operator_pin`)에 기억하도록 고쳤다. **기본 PIN을 쓰는
> 평소 경로는 요청 한 번으로 끝나고 아무것도 묻지 않는다** — 기존 동작 무변화.
> 검증: 기본 서버에 `1234` → `ok:true` / PIN 교체 서버에 `1234` → `invalid_pin`,
> 이어서 `8317` → `ok:true`. `node --check`(docs/05 §9 절차) 통과.

### 3-4. 나머지

- `scripts/mock_serve.py`: `OverheadPressCounter`/`LateralRaiseCounter`로 교체,
  `init_app` 시그니처 정정, `set_mode("squat")`, live 상태에 `overhead`/`lateral` 추가.
  **실제로 띄워서** `/stats.json`과 `/app`(49,022 B) 응답까지 확인함.
- `src/exercise_counter.py` 모듈 docstring의 `pushup (팔꿈치 각도)` → 실제 종목으로.
- `web/README.md`: Vite 보일러플레이트 → 배포본/시안/빌드산출물 3계층 설명으로 교체.
- README §3.4를 "보통 불필요"로. 모델은 이미 커밋되어 있다.
- README 폴더 트리를 실제와 일치시킴(§2-4 표 전부).
- README §10 제목 "모델 / 라이센스" → **"모델 / 제3자 자산"**. 라이센스는 아직 정하지
  않았으므로 "LICENSE 없음 = 저작권 유보"만 명시했다. **LICENSE 파일은 여전히 없다.**
- `README.md` §3.1의 `# 키 등록됨, 비번 없음` 주석 제거(공개 리포).

---

## 4. 검증

| 확인 | 방법 | 결과 |
|---|---|---|
| `/app` = Fluid | 로컬 서버 기동 후 GET | 200, 49,022 B (`web/app`에서) |
| **clone 직후 시나리오** | `_WEB_DIRS`에서 dist 제거 후 GET | **200, 49,022 B** (이전엔 503) |
| 기존 디바이스 폴백 | `web/app` 없이 dist만 | 200 (동작 유지) |
| SPA 폴백 | `/app/nope-route` | 200, index.html |
| React 자산 | `/app/assets/index-CvZFNyLL.js` | 200, `application/javascript` |
| 경로 탈출 | `/app/../../src/http_server.py` | **403** |
| 둘 다 없음 | 가짜 경로 2개 | 503 `web_not_built` |
| PIN 기본/오버라이드/공백 | import 후 값 확인 | `1234` / `8317` / `1234` |
| PIN claim 왕복 | 기본 서버·교체 서버에 HTTP POST | `ok` / `invalid_pin` → `ok` |
| 배포 UI 문법 | `<script>` 추출 후 `node --check` | PASS |
| `run.sh` 문법 | `bash -n` | OK |
| `mock_serve.py` | 실제 기동 + HTTP 확인 | OK |

**실기(UNO Q)에서는 아직 확인하지 않았다.** 디바이스는 `web/app`이 없는 상태이므로
폴백 경로를 타고 지금과 동일하게 뜬다 — 즉 배포 전에도 안전하다. 배포하려면:

```bash
scp web/app/index.html arduino@192.168.0.50:~/health_care_bot/web/app/index.html
```

---

## 5. 남은 것

- **LICENSE 파일** — 라이센스 종류가 정해지지 않아 이번엔 보류했다. §10에 "미정"만 적었다.
- **테스트·CI 없음** — `scripts/test_st3215_serial.py`는 하드웨어 수동 도구다.
  최소한 `/app` 서빙·`app_state` 전이 정도는 CI로 묶을 여지가 있다.
- 디바이스의 낡은 `web/dist/index.html`은 폴백용으로 남아도 무해하지만, `web/app`을
  배포한 뒤에는 헷갈리지 않게 지워도 된다.
- README §3.2·`08`에 남은 `192.168.0.50`은 사설 IP라 그대로 뒀다.

---

## 6. 관련 문서

- 서빙 우선순위: [`02_http_api_and_stats.md`](../02_http_api_and_stats.md) §5
- 배포 절차: [`05_web_ui_fluid.md`](../05_web_ui_fluid.md) §9, §9-1
- 폴더 구조: [`00_project_blueprint.md`](../00_project_blueprint.md) §5
- 앞 세션: [`2026-09-08_01`](2026-09-08_01_docs_synced_to_runtime_verified_on_device.md)

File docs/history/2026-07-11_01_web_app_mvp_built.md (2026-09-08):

# 2026-07-11 — Health Care Bot Live PWA 최초 구현

> **[2026-09-08 보안 마스킹]** 공개 리포 노출을 막기 위해 adb serial(기기 고유 식별자)를 가렸다.
> 기록 내용 자체는 바꾸지 않았다. 원칙: [`00`](../00_project_blueprint.md) §7-1.

## 시점

2026-07-11

## 사건

`APP_PLAN.md` + `health_care_bot_mvp_screen_plan.md`(화면 분리형 개정안) 기반으로
모바일 웹앱(PWA) 최초 구현 완료. 백엔드에 세션/제어권 API 신규 추가, 프론트엔드
Vite+React+TS 프로젝트를 처음부터 구축.

## 배경

기존 `http_server.py`는 `GET /`, `/stream.mjpg`, `/stats.json`만 제공하는
디버그 모니터링 전용이었다. 시연 관람객이 QR로 접속해 라이브 화면·운동
카운트를 보고, 운영자가 PTZ를 직접 조작하려면 정적 앱 서빙 + mutation API +
권한 분리가 필요했다.

## 결과

**백엔드** (`src/`)
- `app_state.py` 신규: 세션(시작/일시정지/재개/리셋/종료) + PIN 기반 운영자
  제어권 lock (60초 TTL + heartbeat 연장)
- `ptz_controller.py`: `manual_pan/tilt/center`, `set_auto_track` 추가 —
  자동 추적과 수동 조작이 충돌하지 않도록 분리
- `http_server.py`: `POST /api/ptz`, `/api/mode`, `/api/session/*`,
  `/api/control/*` + `/app` 정적 파일 서빙
- `main.py`: 위 상태 객체를 추론 루프에 연결, 앱에서 실시간 모드 변경 반영

**프론트엔드** (`web/`) — Vite + React + TypeScript
- 4화면(라이브/운동/카메라 제어/더보기) + 모바일 하단 네비 / 데스크톱
  사이드 네비, CSS 변수 기반 디자인 시스템(Dragonwing 톤)
- 추후(같은 날) 레퍼런스 이미지에 가까운 세이지그린 테마를 `data-theme`
  토글로 추가 — 컴포넌트 코드 변경 없이 CSS 변수 재정의만으로 구현
  (`web/ARCHITECTURE.md` §7)

**검증**: 카메라/모델 없이 `scripts/mock_serve.py`(신규, 실배포 미사용) +
Playwright로 뷰어/운영자 × 모바일/데스크톱 화면을 실제 브라우저에서
스크린샷 확인, 콘솔 에러 0건. PIN claim 직후 배지가 다음 폴링까지 늦게
갱신되는 문제를 발견해 낙관적 로컬 상태로 즉시 수정.

실제 UNO Q 디바이스(`unoq-korea01`, adb serial은 `adb devices`로 확인)에도 배포해
컨테이너 기동 로그로 `/app` 서빙 확인 (상세: `2026-07-11_02_device_deploy_camera_not_detected.md`).

## 다음 단계

- USB 카메라 재연결 후 실제 라이브 스트림 e2e 확인
- PTZ 시리얼(`/dev/ttyACM0`) 연결 후 수동 조작 실기 검증
- 네트워크 의존성 완화책(mDNS/핫스팟)은 시연 환경 확정 후 착수
  (`web/ARCHITECTURE.md` §8)

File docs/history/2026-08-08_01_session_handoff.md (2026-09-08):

# 2026-08-08 세션 핸드오프 — 경비 모드 신설 · PTZ 모드전환 버그 · 원격 접속(Tailscale)

> **[2026-09-08 보안 마스킹]** 공개 리포 노출을 막기 위해 Tailscale 주소·Tailscale IP·공유기 SSID를 가렸다.
> 기록 내용 자체는 바꾸지 않았다. 원칙: [`00`](../00_project_blueprint.md) §7-1.

> 다음 세션은 이 문서부터 읽으면 오늘까지의 맥락이 잡힙니다. 웹 UI 구조는
> [`05_web_ui_fluid.md`](../05_web_ui_fluid.md), API 계약은
> [`02_http_api_and_stats.md`](../02_http_api_and_stats.md) 참고 (오늘 guard 관련 갱신됨).

---

## 1. 한 줄 요약

운동과 완전히 분리된 **경비(guard) 모드**를 새로 만들었다(홈 자세 대기 → 사람 감지 시
추적+자동촬영 → 10초 미검출 시 홈 복귀). 그 과정에서 PTZ 모드전환 잠금 버그·
`docker/run.sh` tty 버그·QR 정적이미지 함정을 고쳤고, **정전으로 인한 공유기 무선
클라이언트 격리 고착**이라는 오늘 하루 대부분을 잡아먹은 네트워크 문제를 풀었다.
마지막으로 **Tailscale + Funnel로 외부(다른 와이파이/데이터)에서도 접속 가능**하게
만들었다.

---

## 2. 지금 돌고 있는 것 (현재 상태)

- 디바이스: `arduino@192.168.0.50` (IP는 DHCP라 재부팅 시 또 바뀔 수 있음 — 안 되면
  `arp`/ping 스캔으로 재탐색. [`reference_unoq_github.md`](../../../../unoq-companion-robot/README.md)류
  메모리에 최신 IP 기록해둠).
- 서비스: `screen -S hcb` 세션 안에서 `bash docker/run.sh` 실행 중.
- **로컬 LAN**: `http://192.168.0.50:8080/app`
- **외부(Tailscale Funnel, 필요할 때만 켤 것)**: `https://<기기이름>.<tailnet>.ts.net/app`
  - 켜기: `sudo tailscale funnel --bg 8080`
  - 끄기: `sudo tailscale funnel --https=443 off` (다 보여준 뒤 반드시 끌 것 — 이 앱은
    PIN(`1234`) 하나 말고 실질적 인증이 없어서, 링크 아는 사람 누구나 카메라/PTZ/경비
    사진 다 볼 수 있음)
  - UNO Q의 Tailscale IP: `tailscale ip -4`로 확인 (자기 기기끼리는 Funnel 없이 이걸로도 접속 가능)
- PTZ pitch 부호: **`PITCH_SIGN=-1`이 새 기본값** (2026-08-06 짐벌 재조립 이후 확정,
  `docker/run.sh`/`main.py`/`ptz_controller.py` 전부 반영됨).

**실행/중지:**
```bash
ssh arduino@192.168.0.50
cd ~/health_care_bot && bash docker/run.sh
docker stop health-care-bot
```

---

## 3. 오늘 한 일 (주제별)

1. **경비(guard) 모드 신설** — 운동이 아닌 4번째 모드. 전환 즉시 홈(중앙) 정렬 → 5초
   무장 딜레이 → 사람 감지 시 원본 프레임을 `captures/`에 저장 + `guard_log.jsonl`에
   로그 → 10초 이상 미검출이면 자동으로 홈 복귀. PTZ는 무릎/어깨 우선순위 없는
   `person_center_normalized` 기반 전신 추적(`track_mode="guard"` 신설).
2. **PTZ 모드전환 시 잠금 안 풀리는 버그 수정** — 스쿼트에서 잠긴 채 상체운동으로
   바꿔도 안 움직이던 문제. `set_track_mode()`가 실제 전환 시 `locked`를 강제 리셋.
3. **`docker/run.sh` tty 버그 수정** — `-it` 고정이라 비대화형 SSH 등 tty 없는
   세션에서 `the input device is not a TTY`로 조용히 죽던 문제. tty 유무를 감지해
   없으면 `-it` 없이 뜨도록 수정.
4. **QR 정적이미지 함정 해결** — 모바일 접속 QR이 특정 시점 IP로 미리 렌더링한
   그림이라 IP 바뀌어도 절대 안 바뀌는 함정이었음. 외부 CDN 없이(로봇 Wi-Fi에
   인터넷 없을 수 있음) 브라우저 안에서 그 자리에서 QR을 인코딩하는 자체 생성기
   내장(`qrSvg()`, 버전1~4·ECC-M·마스크0 고정). jsqr로 실제 디코드 검증 완료.
5. **네트워크 대장정 (오늘 몇 시간 소모)** — 결론: **정전으로 집 공유기(5GHz 대역)가
   비정상 재부팅 → 무선 클라이언트 격리 상태로 고착**. PC는 사실 유선으로 나가고
   있어서 무선 격리를 안 타고 있었을 뿐이었고("PC는 되는데 폰만 안 됨"이 오히려
   격리의 증거였음), 문제의 AP를 한 번 더 깨끗하게 재시작하니 해결. 상세 진단
   순서는 [[project_hcb_demo_network]] 메모리에 기록.
6. **Tailscale + Funnel로 원격 접속 구축** — 다른 와이파이/모바일데이터에서도
   `https://<기기이름>.<tailnet>.ts.net/app`으로 접속 가능. 이 과정에서
   **프론트엔드가 API 주소를 `:8080`으로 하드코딩**하고 있어 Funnel(외부 포트가
   8080이 아님)에서 스트림/상태가 안 들어오던 버그도 같이 발견·수정
   (`location.origin`을 그대로 쓰도록 변경).
7. **모바일 UI 개선 3건**:
   - 링 안 숫자가 모바일에서 살짝 어긋나던 버그 — `<svg width="96" height="96">`
     하드코딩이 84px 컨테이너보다 커서 삐져나간 것. `width/height:100%`로 수정.
   - 무장 중 큰 숫자가 촬영 매수(예: "18")를 보여주면서 라벨은 "무장 중"이라
     안내문구("2초 뒤...")랑 안 맞던 버그 — 무장 전엔 숫자=남은 초로 통일.
   - "무장" 용어를 "N초 뒤 경비를 시작합니다"로 순화.
8. **경비 모드 PTZ 패널 모바일 레이아웃 재구성** — "최근 촬영" 상시 스트립이 화면을
   너무 잡아먹어 카메라 뷰가 눌리던 문제 → 버튼+시트(모달)로 전환. "직접 조작" 탭의
   조이스틱을 오른쪽으로 옮기고 왼쪽에 "🖼 사진 보기"/"● 직접 촬영" 버튼 추가.
9. **"직접 촬영" 버튼 쿨다운 공유 버그 수정** — 자동 감지랑 같은 5초 쿨다운을 써서,
   사람이 화면에 계속 있으면(테스트 중 본인) 자동 촬영이 쿨다운을 계속 선점해
   버튼을 눌러도 조용히 씹히던 문제. 수동 촬영은 쿨다운 무시하고 무조건 즉시
   촬영하도록 분리 + 버튼에 "촬영 중…/촬영됨!" 시각 피드백 추가.
10. **캡처 목록 API 신설** — `GET /api/guard/captures`(최근 N개), `GET /captures/<file>`
    (이미지 서빙), 웹에서 썸네일 그리드 + 탭하면 라이트박스로 크게 보기.

---

## 4. 코드 변경 (건드린 파일)

**백엔드 (`src/`):**
- `app_state.py` — guard 모드/무장타이머/촬영쿨다운/수동촬영 플래그 상태 전체.
- `guard_capture.py` (신규) — 사람 감지 판정(어깨+엉덩이 keypoint) + JPEG 저장 + 로그.
- `ptz_controller.py` — `track_mode="guard"` 추가(전신 추적 타깃), guard 진입 시 홈
  정렬, 10초 미검출 홈 복귀(`_guard_home`), 모드전환 시 `locked` 강제 리셋,
  `pitch_sign` 기본값 `-1`.
- `main.py` — guard 분기(스켈레톤 오버레이 생략, 자동/수동 촬영 트리거),
  `--pitch-sign` 기본값 `-1`.
- `http_server.py` — `/api/guard/capture-now`, `/api/guard/captures`,
  `/captures/<file>` 라우트 추가.
- `docker/run.sh` — `PITCH_SIGN`/`YAW_SIGN` 환경변수 지원(기본 -1/1), tty 감지 후
  `-it` 조건부 적용, `python3 -u`(무버퍼링, 로그 캡처용).

**프론트 (`web/dist/index.html`):**
- 설정(⚙️) 시트에 "운동 모드 / 경비 모드" 전환 세그먼트 신설 — 하단 운동
  세그먼트(스쿼트/숄더프레스/레터럴)와 완전히 분리.
- 모바일 접속(QR)을 별도 아이콘(⊞)/시트로 분리.
- 자체 QR 생성기(`qrSvg()`) 내장 — 정적 이미지였던 걸 런타임 인코딩으로 교체.
- `API` 상수를 `location.origin`으로 변경(포트 하드코딩 제거).
- 경비 모드 링/숫자 로직(`paintGuardRing`) — 무장 전/후 다른 숫자·라벨, "reps" 공유
  변수 동기화 버그 수정.
- 경비 모드 "직접 조작" 패널 — 조이스틱 우측 배치 + 좌측 "사진 보기"/"직접 촬영" 버튼.
- 촬영 갤러리 시트(`#capturesSheet`) + 라이트박스(클릭 시 확대).
- `.ring svg{width:100%;height:100%}` 정렬 버그 수정.

---

## 5. 다음 할 일 (미해결, 우선순위)

1. **스쿼트↔숄더프레스 전환 시 pitch 범위 문제** — 무릎-어깨 각도차가 ±30° 범위
   거의 끝까지 써서, 카메라-사람 거리가 가까우면 전환 중 사람을 놓칠 수 있음.
   사람이 카메라에서 더 멀리 서서 재테스트 필요(가설: 거리 늘리면 각도차 줄어듦).
2. **동시 뷰어 2명(PC+폰) 이상일 때 FPS 저하** (10→8 관측) — Python GIL 스레드
   경합 + Tailscale Funnel 암호화 오버헤드가 겹친 것으로 추정. `--jpeg-quality`를
   낮추는 게 쉬운 완화책이나 아직 미적용(run.sh에 옵션 미노출).
3. 캡처 파일이 계속 쌓이는데 자동 정리(오래된 것 삭제) 로직 없음 — 필요하면 추가.

---

## 6. 오늘 새로 안 함정 (재발 방지)

- **웹 프론트에서 API 주소를 특정 포트로 하드코딩하지 말 것** — `location.origin`을
  그대로 써야 리버스 프록시/터널(Funnel 등) 어떤 경로로 접속해도 깨지지 않는다.
- **정적으로 미리 렌더링해둔 QR/URL 이미지는 절대 만들지 말 것** — IP가 바뀌는
  프로젝트라 반드시 런타임에 다시 계산해서 그려야 한다.
- **"PC는 되는데 폰만 안 됨"이 무선 격리를 배제하는 근거가 아니다** — PC가 실제로
  같은 무선 경로를 타고 있는지 `Find-NetRoute`(Windows)로 먼저 확인할 것. 유선으로
  나가고 있으면 격리 테스트 자체가 무의미하다.
- **SSH 세션에 PC용 명령(`py -3.14`, PowerShell 문법)을 그대로 붙여넣기 쉬움** —
  디바이스 프롬프트(`arduino@unoq-korea01:~$`)인지 항상 먼저 확인.
- **PowerShell로 `tar | ssh` 파이프하면 바이너리가 깨짐** — Git Bash에서 하거나,
  파일로 먼저 tar 떠서 scp로 옮길 것.
- **자동 감지와 수동 트리거가 같은 쿨다운/락을 공유하면 안 됨** — 사용자가 명시적으로
  누른 버튼은 자동화 로직의 상태(쿨다운 등)와 무관하게 항상 즉시 반응해야 한다.
  안 그러면 "가끔 안 먹히는" 것처럼 보여서 디버깅하기 어렵다.
- **SVG에 `width`/`height` 속성을 하드코딩하면 CSS로 컨테이너 크기를 줄여도 그
  값 그대로 렌더링돼 삐져나온다** — 반응형이 필요하면 `width:100%;height:100%`로
  덮어써야 한다(viewBox는 내부 좌표계만 정의, 실제 렌더 크기는 별개).

---

## 7. 관련 메모리 (프로젝트 외부, `.claude/projects/.../memory/`)

- `project_health_care_bot.md` — 오늘 섹션("경비 모드 신설 + QR 정적 이미지 함정")에
  요약 반영됨.
- `project_hcb_demo_network.md` — 정전 후 AP 격리 고착 사례 상세 진단 순서 기록.

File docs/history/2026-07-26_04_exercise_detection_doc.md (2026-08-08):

# 2026-07-26 — 운동 인식·카운팅 설계 문서 작성

## 시점

2026-07-26. 종목 개편([`_02`](2026-07-26_02_pushup_removed_overhead_lateral_added.md))과
PTZ 상체/하체 추적([`_03`](2026-07-26_03_ptz_track_mode_upper_lower_body.md))을 마친 뒤,
"스쿼트·숄더프레스가 어떻게 동작하는지" 정식 문서화 요청.

## 무엇을

[`docs/exercise_detection.md`](../04_algorithm_exercise.md) 신규 작성 — 운동 감지·카운팅의
**설계 레퍼런스**. 히스토리(경위)와 달리 "지금 어떻게 동작하는가"를 정리한 문서다.

담은 내용:
- 큰 그림(카메라→MoveNet 17kp→각도→RepCounter→PTZ)과 2D 포즈 전제.
- 공통 엔진 `RepCounter`: UP↔DOWN 상태기계 + 히스테리시스 + dwell.
- 종목별 각도·임계·rep 정의:
  - 스쿼트 = 무릎(hip-knee-ankle), down<100/up>140.
  - 숄더프레스 = 어깨올림(elbow-shoulder-hip), down<60/up>140.
  - 레터럴 = 같은 각도, down<35/up>80.
- 왜 각도 하나로 상체 두 종목을 다 세는지(팔 내림10°/수평90°/머리위165°).
- 모드 선택(자동분류 없음, 웹에서 /api/mode).
- PTZ 상체/하체 추적 표.
- 왜 푸시업을 뺐나(2D depth 문제).
- 튜닝 지점 표 + 파일 지도.

## 관련

- 문서: [`docs/exercise_detection.md`](../04_algorithm_exercise.md)
- 구현 히스토리: [`_02`](2026-07-26_02_pushup_removed_overhead_lateral_added.md),
  [`_03`](2026-07-26_03_ptz_track_mode_upper_lower_body.md)

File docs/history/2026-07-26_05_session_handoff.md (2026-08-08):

# 2026-07-26 세션 핸드오프 — 애플 UI 통일 · 운동 종목 개편 · 상체/하체 추적

> 다음 세션은 이 문서부터 읽으면 오늘까지의 맥락이 잡힙니다. 하드웨어/서보/PTZ
> 저수준 배경은 `docs/HANDOFF.md`(07-17), 종목 감지 설계는
> `docs/exercise_detection.md` 참고.
>
> **경로 안내 (2026-07-30 재편)** — 위 두 문서는 `docs/00~09` 번호 체계로 이관됐습니다:
> HANDOFF → [`06_hardware_calibration.md`](../06_hardware_calibration.md)(하드웨어 값) ·
> [`07_runbook.md`](../07_runbook.md)(실행/환경) · [`08_troubleshooting.md`](../08_troubleshooting.md)(함정),
> exercise_detection → [`04_algorithm_exercise.md`](../04_algorithm_exercise.md).
> 전체 지도는 [`00_project_blueprint.md`](../00_project_blueprint.md) §6.

---

## 1. 한 줄 요약

애플 디자인 라이브 UI를 만들어 **:8080/app 하나로 통일**했고, 운동 종목을
**스쿼트 + 숄더프레스 + 레터럴레이즈**(푸시업 삭제)로 개편, **PTZ 추적을 종목별
상체/하체로 분리**했다. 웹 UI에서 종목 선택 + 누구나 조종(공유 제어권).

---

## 2. 지금 돌고 있는 것 (현재 상태)

- 디바이스(`arduino@192.168.0.45`)에서 **run.sh 서비스 실행 중** (screen 세션 `hcb`).
- **`http://192.168.0.45:8080/app` = 애플 "Fluid" 디자인** (라이브 로봇 카메라 + 실제 데이터).
- 카메라 = `/dev/video2` (run.sh가 USB 카메라 자동탐색), 서보 = `/dev/ttyACM0`, fps ~11.
- 운동 종목 = **squat / overhead / lateral**, 웹 UI에서 선택.
- 제어 = 공유 제어권 `client_id="hcb-demo"` + PIN `1234` → 접속한 누구나 조종.

**실행/중지:**
```bash
ssh arduino@192.168.0.45
cd ~/health_care_bot && bash docker/run.sh      # 카메라 자동(video2), /app=애플
docker stop health-care-bot                      # 중지
```
접속: `http://192.168.0.45:8080/app` (운영자 PTZ: 설정 없이 바로 조종됨 / 뷰어와 동일 화면)

---

## 3. 오늘 한 일 (주제별)

1. **애플 디자인 스킬 설치** — Emil Kowalski `npx skills@latest add emilkowalski/skills`
   (apple-design 외 5종, 전역 `~/.claude/skills`). `review-animations`는 사용자 직접 호출 전용.
2. **라이브 시안 2종 신규** (`design_demos/`):
   - `live_frontend-design.html` "Field Optics" (광학 계기)
   - `live_apple-design.html` "Fluid" (스프링 물리) — **이게 메인**
3. **로봇 실카메라 연동** — `/stream.mjpg` + `/stats.json` 폴링, 레티클=실제 추적 좌표,
   없으면 getUserMedia 데모 폴백.
4. **공유 제어권** — 모든 클라이언트가 `hcb-demo` 공유 → 잠금 없이 누구나 조종(마지막 명령 우선).
   조이스틱=실서보, 모드/auto_track=실제 API.
5. **Fluid 개선** — PTZ 자동추적↔직접조작 토글(자동=텔레메트리 FPS/추론/CPU온도/RAM,
   수동=조이스틱), 설정 기어+QR 모바일 접속, **컴퓨터/모바일 분리 레이아웃**
   (PC=큰 카메라+정보 아래, 폰=한 화면).
6. **8080 통일** — `web/dist/index.html`=애플 페이지(자체포함 HTML), stock은
   `index.html.stock.bak` 백업. `run.sh`에 카메라 자동탐색(video2) 굽음.
7. **모바일 접속 디버그** — 폰 접속 실패 → **폰 랜덤 MAC** 원인 규명·해결
   (`issues/2026-07-26_01`).
8. **운동 종목 개편** — 푸시업 삭제, 숄더프레스·레터럴 추가, 자동분류 제거→웹 명시 선택
   (`history/2026-07-26_02`).
9. **PTZ 상체/하체 추적 분리** — 스쿼트=무릎, 상체운동=어깨(머리 위 팔 안 잘리게)
   (`history/2026-07-26_03`).
10. **문서화** — `docs/exercise_detection.md` 설계문서 (`history/2026-07-26_04`).

---

## 4. 코드 변경 (건드린 파일)

**백엔드 (`src/`):**
- `exercise_counter.py` — PushupCounter 자리에 OverheadPressCounter(60/140)·LateralRaiseCounter(35/80).
- `angles.py` — `shoulder_elev_angle`(elbow-shoulder-hip) 추가.
- `main.py` — 종목 3개, `select_counter`(자동분류 제거), `compute_angle` 분기, stats 키
  squat/overhead/lateral, `ptz.set_track_mode(exercise)` 호출.
- `app_state.py` — mode 유효값 (squat/overhead/lateral), `session_finish(snaps)` 일반화.
- `http_server.py` — init_app/세션 API에 3 카운터.
- `ptz_controller.py` — `track_mode`(lower/upper), `set_track_mode`, `_target`(어깨/무릎),
  모드별 pitch 기준·데드존.
- `pose_utils.py` — `shoulder_center_normalized`.
- `docker/run.sh` — 카메라 USB 자동탐색(video2), `--mode auto`→`--mode squat`.

**프론트:** `web/dist/index.html`(=애플 Fluid, 소스 `design_demos/live_apple-design.html`) —
세그먼트 3버튼(스쿼트/숄더프레스/레터럴), 활성 모드 카운터 표시.

---

## 5. 디자인 자산 현황 (총 8종)

- **React 앱 시안 6종** (`web/src/versions/`, `registry.ts`): CALM(기본)·PULSE·AURORA·
  CORE·CARE(rehab)·LIVE(session). **단, 빌드 산출물이 Fluid로 덮여 지금 서빙 안 됨**
  (보려면 빌드 or 예전 컴파일본 서빙). `web/DESIGN.md`는 07-21 기준이라 "CALM 1종"으로
  오래됨 — registry가 최신(6종).
- **독립 HTML 2종** (`design_demos/`): Field Optics, Fluid(=현재 /app).
- 목업 보드: `docs/design_refs_2026-07-25/candidate-board.html` (정적, 빌드없이 열림).
- 백업: `web/dist/index.html.stock.bak`(stock React), `backup/web_2026-07-20_pre_redesign/`.

---

## 6. 다음 할 일 (실측 필요, 우선순위)

1. **운동 3종 실제 사람으로 카운팅 검증·임계 튜닝** — 임계값은 합리적 기본값일 뿐.
   누락/중복 시 조정. (레터럴은 팔꿈치 곧게, 정면 응시 필요)
2. **PTZ 상체 프레이밍 실측** — 숄더프레스/레터럴 시 머리 위 팔이 프레임에 남는지.
   잘리면 `ptz_controller.py::pitch_target_y_upper`를 0.64→0.68~0.72로.
3. **스쿼트 회귀 확인** — 종전과 동일하게 추적/카운트되는지.
4. (선택) React 6종 정리 or 애플 Fluid로 완전 확정.

---

## 7. 오늘 새로 안 함정 (재발 방지)

- **run.sh 하드코딩 인자 ↔ argparse 동기화**: argparse `--mode`에서 `auto` 뺐더니
  run.sh의 `--mode auto`가 컨테이너를 즉시 죽였다. `--rm`이라 `docker logs`엔 안 남음
  → `run.sh > /tmp/hcb_run.log 2>&1`로 캡처해서 진단. argparse choices 바꿀 땐 run.sh도 확인.
- **폰 랜덤 MAC** = `ERR_ADDRESS_UNREACHABLE` (그 네트워크에서 랜덤MAC 끄면 해결).
  상세 `issues/2026-07-26_01`.
- **애플 페이지는 정적 HTML** → `npm run build` 하면 `web/dist/index.html`이 stock으로
  덮인다. 애플 유지하려면 재배포(백업 `index.html.stock.bak`).
- **카메라 노드는 부팅마다 바뀜** — run.sh가 자동탐색하지만, 안되면
  `for v in /sys/class/video4linux/video*; do echo "$(basename $v) $(cat $v/name)"; done`.
- SSH stdin 파일전송 시 `pkill -f "http.server 8777"`는 **자기 셸까지 매칭**해 세션이
  끊긴다(exit 255) — PID로 kill 하거나 bracket 트릭.

---

## 8. 관련 문서 / 히스토리 (오늘)

- 설계: [`04_algorithm_exercise.md`](../04_algorithm_exercise.md) (당시 `exercise_detection.md`)
- [`2026-07-26_01`](2026-07-26_01_apple_design_ui_live_and_8080_unify.md) 애플 UI + 8080 통일
- [`2026-07-26_02`](2026-07-26_02_pushup_removed_overhead_lateral_added.md) 종목 개편
- [`2026-07-26_03`](2026-07-26_03_ptz_track_mode_upper_lower_body.md) PTZ 상체/하체
- [`2026-07-26_04`](2026-07-26_04_exercise_detection_doc.md) 설계 문서화
- 이슈: [`issues/2026-07-26_01`](../issues/2026-07-26_01_mobile_web_access_fails_random_mac.md) 폰 랜덤 MAC

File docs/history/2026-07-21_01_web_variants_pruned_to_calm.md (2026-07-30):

# 2026-07-21 — 웹 시안 4종 → CALM 1종(후보)으로 정리

## 시점

2026-07-21. 전날 만든 디자인 시안 4종
([`2026-07-20_01`](2026-07-20_01_web_redesign_four_variants.md))을 검토한 뒤.

## 사건

시안 4종 중 **CALM만 후보로 남기고 INSTRUMENT·ALMANAC·STADIUM은
삭제**했다. CALM도 확정이 아니라 **후보 상태**로 둔다 — 백업 유지,
문서에 후보로 표기, 프로덕션 승격(원본 대체·백업 삭제) 안 함.

## 삭제한 것

- 폴더: `src/versions/{instrument,almanac,stadium}/` (각 `.tsx` + `.css`)
- 훅: `src/hooks/useSeries.ts` — 스파크라인용이었고 INSTRUMENT·STADIUM만
  쓰던 것이라 두 시안 삭제로 죽은 코드가 됨
- 폰트: `spline-sans-mono-var.woff2`, `newsreader-var.woff2`,
  `newsreader-var-italic.woff2`, `archivo-2ax.woff2` + `fonts.css` 항목
- 잔재: `pretendard-var-subset.woff2` (첫 서브셋 시도의 미사용 산출물)

남은 디스플레이 서체는 **Gabarito(CALM)** 하나. 한글 Pretendard 조각은
그대로 — CALM의 글자를 이미 전부 포함하므로 재생성 불필요
(원한다면 `python scripts/subset_pretendard.py`로 kr-core를 조금 줄일 수는 있음).

## 왜 시안 전환 구조를 안 지웠나

`registry.ts`·`VersionPicker`·`useVersion`·`App`의 lazy 라우팅을
**일부러 남겼다.** 후보가 하나뿐이면 없어도 되지만:

- CALM이 "확정 UI"가 아니라 "후보"임을 구조로 드러낸다. 우상단
  `시안 정보` 버튼(키 `v`)을 열면 "로봇 확정 전 검토 중인 후보입니다"와
  함께 후보 목록이 뜬다.
- 나중에 후보를 다시 늘리거나 교체할 때 그대로 쓴다. 시안을 `versions/`에
  추가하고 `VERSIONS` 배열에 한 줄 넣으면 끝.

`VERSIONS`는 이제 `[calm]`, `DEFAULT_VERSION = 'calm'`, `VersionId = 'calm'`.
삭제된 시안 주소(`?ui=instrument` 등)는 `isVersionId`가 걸러 CALM으로
폴백한다.

## 검증

`npm run build` 통과(청크가 시안별 5벌 → CALM 1벌로 줄어듦). Playwright로:

- CALM이 Gabarito를 실제 로드, 가로 스크롤 없음, tabular-nums 적용
- `?ui=instrument`/`?ui=stadium`이 CALM으로 폴백, 삭제 시안 루트
  (`.ins`/`.alm`/`.std`) 잔재 없음
- 피커 후보 1개, 콘솔 에러 없음

## 관련

- [`web/DESIGN.md`](../../web/DESIGN.md) §2에 남은 후보 CALM + 삭제 시안
  3종(참고)·백업 경로 정리
- 되돌리기: `backup/web_2026-07-20_pre_redesign/src/versions/` 에서 폴더와
  `fonts.css`·폰트 파일을 가져오면 됨

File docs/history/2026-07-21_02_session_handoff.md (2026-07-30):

# 2026-07-21 — 세션 핸드오프 (웹 시안 · 디바이스 실행 · 성능 조사 · PTZ)

다음 세션에서 바로 이어받기 위한 상태 스냅샷 + 미결정 + 재현 명령.
이전 개요: [`2026-07-20_01`](2026-07-20_01_web_redesign_four_variants.md),
[`2026-07-21_01`](2026-07-21_01_web_variants_pruned_to_calm.md).

---

## 1. 지금 어떤 상태인가 (한눈에)

- **웹 시안 5종**이 시안 피커에 등록됨: `CALM · PULSE · AURORA · CARE(rehab) · LIVE(session)`.
  기본값 `calm`. 전환: 화면 `시안` 버튼 / 키 1–5 / URL `?ui=<id>`.
- **디바이스에서 앱이 실기로 실행 중** (UNO Q, `arduino@192.168.0.45`). 새 웹(dist) 배포 완료.
  카메라·서보 연결됨, HTTP 8080 서빙, 추론 ~11.4 FPS.
- **성능 조사 결론 확정**: 시스템은 **invoke(추론) 바운드**. 화면/인코딩 끄기·카메라레이트
  낮추기로는 FPS 안 오름(실측). 모델 안 바꾸면 유일한 큰 레버는 **NPU 델리게이트**.
- **PTZ 추적/관성 알고리즘**은 이번 세션에 코드 변경 없음. 설명·구조도만 산출.

---

## 2. 웹 — 디자인 시안 현황

경로: `web/src/versions/<id>/`, 등록: `web/src/versions/registry.ts`, 라우팅: `web/src/App.tsx`.

| id | 이름 | 성격 | 제작 |
|---|---|---|---|
| `calm` | CALM | 숨쉬는 코치 (Gentler Streak·Apple Fitness) · **기본값** | 이번 세션(초기 4종 중 유일 생존) |
| `pulse` | PULSE | 밝은 프로덕트 콘솔 (Toss·Dragonwing). 스쿼트+푸시업 2카드, STEP, +1 플로터 | 사용자 목업 기반 |
| `aurora` | AURORA | 유리 대시보드 (글래스모피즘). **플로팅 하단 바** + 3뷰(라이브/장치/제어) | 사용자 목업 기반 |
| `rehab` | CARE | 신뢰하는 재활 코치 | **사용자 제작** (내가 안 만든 파일) |
| `session` | LIVE | 세션 집중 스포츠 | **사용자 제작** |

- **삭제됨**(백업에 있음): INSTRUMENT·ALMANAC·STADIUM → `backup/web_2026-07-20_pre_redesign/src/versions/`.
- **원본 웹 백업**: `backup/web_2026-07-20_pre_redesign/` (되돌리려면 여기서 복원).
- 시안끼리 CSS/마크업 공유 안 함 (lazy 분리). 공유는 데이터+동작(훅)뿐.

### 공통 인프라
- **데모 모드** `?demo=1` — 로봇 없이 합성 데이터+가짜 골격. 실제 stats 오면 자동 해제.
- 훅: `useStats`(폴링+연결+데모폴백), `useMjpeg`, `useRepPulse`, `usePressRepeat`, `useVersion`.
  `useSeries`는 CALM 정리 때 삭제 → AURORA가 로컬 `useRolling`으로 자체 보유.
- **폰트 self-host**: Pretendard 2.0MB를 `web/scripts/subset_pretendard.py`로 unicode-range
  46조각화 (`web/public/fonts/pretendard/`). 원본은 `web/fonts-src/`(served 아님).
  한국어 문구 크게 바꾸면 재실행: `cd web && python scripts/subset_pretendard.py`.
- 설계 근거 문서: [`web/DESIGN.md`](../../web/DESIGN.md). (아직 CALM 위주라 PULSE/AURORA 미반영 — **갱신 필요**.)

### 미결정 (웹)
- **시안 확정** — 5종 중 무엇을 최종으로? (또는 계속 후보 병존)
- 푸시업 폐기 논의 → **취소됨**(원복). 현재 PULSE는 스쿼트+푸시업 둘 다 표시.
- `web/DESIGN.md`에 PULSE/AURORA/CARE/LIVE 반영 안 됨.

---

## 3. 디바이스 — 실행 상태 & 재현

**접속**: `ssh arduino@192.168.0.45` (키 인증, 비번 불필요). 호스트명 `unoq-korea01`.
**앱 위치**: `~/health_care_bot` (git 저장소 아님, 파일 복사 배포). **Docker로 실행**.
**런타임**: 컨테이너 `health-care-bot:22.04`. `~/.venvs/hcb`는 안 씀(의존성 없음).

### ⚠️ 지금 컨테이너가 **실행 중**입니다
- 카메라 ON, 서보 torque ON(움직임), HTTP 8080. 세션 종료 시 정리하려면:
  ```bash
  ssh arduino@192.168.0.45 'docker stop health-care-bot'
  ```

### 브라우저 접속 (같은 네트워크)
- `http://192.168.0.45:8080/app/?ui=aurora` (뷰어) · `...&role=operator` (조작, **PIN 1234**)
- 실기라 카메라 앞에 사람이 서야 추적·카운트 동작.

### 웹 재배포 (로컬 dist → 디바이스)
```bash
cd web && npm run build
tar -czf - dist | ssh arduino@192.168.0.45 \
  'cd ~/health_care_bot/web && rm -rf dist && tar -xzf -'
# http_server가 매 요청 디스크에서 읽으므로 컨테이너 재시작 불필요
```

### 앱 시작 (detached, run.sh는 -it라 비대화형 ssh 불가 → 직접 docker run)
```bash
ssh arduino@192.168.0.45 'cd ~/health_care_bot && \
  docker rm -f health-care-bot 2>/dev/null; \
  docker run -d --name health-care-bot --net host \
    --device /dev/video0 --device /dev/video1 --device /dev/ttyACM0 \
    -v "$PWD:/work" -w /work health-care-bot:22.04 \
    python3 /work/src/main.py /work/models/movenet_thunder_int8.tflite \
      --mode auto --camera 0 --serial /dev/ttyACM0 --serve 8080'
```

### 🔴 부팅마다 바뀌는 것 (매번 확인)
- **카메라 노드**: `/dev/videoN`이 부팅마다 바뀜. 이번엔 USB 카메라=video0/1, venus 코덱=video2/3
  → `--camera 0`. 다음 부팅엔 다를 수 있음. 확인:
  ```bash
  for f in /sys/class/video4linux/video*/name; do echo "$(basename $(dirname $f)): $(cat $f)"; done
  ```
  (`qcom-venus`가 아닌 노드가 진짜 카메라)
- **USB VBUS 이슈**: 카메라·서보(CH343 ttyACM0)는 UNO Q 직결 시 전원 안 가 인식 안 됨.
  **셀프파워 USB 허브** 필수. `lsusb`에 `ARC Camera`+`QinHeng CH343`+`Huasheng HUB` 떠야 정상.
- 서보 노드: 보통 `/dev/ttyACM0`.

---

## 4. 성능 조사 — 결론 (실측)

**질문**: 화면/스트리밍 끄면 FPS 오르나? 모델 교체 없이 추론 속도 올릴 수 있나?

### 실측 결과
| 실험 | 결과 |
|---|---|
| 인코딩 ON(serve 8080) vs OFF(serve 0) | FPS 11.34 ↔ 11.41 = **~0 차이** (오차) |
| 카메라 15fps 캡 시도 | 카메라가 무시(actual=30.5 유지) → 비교 불가 |
| CPU 4코어 | 전부 **2016MHz = 최대** (schedutil 이미 최대까지 밀어붙임) |
| CPU 명령셋 | `asimd`만, **`asimddp`(INT8 dotprod) 없음** → INT8 고속 커널 못 씀 |
| 온도(추론 중) | 65~73°C (throttle 전) |

### 왜 안 오르나
- 루프 직렬(`grab→invoke→draw→encode`), **invoke가 지배**. invoke 구간 4코어 100%,
  그리기/인코딩 구간 1코어(3코어 놀음) → 평균 CPU ~85%.
- 화면 끄면 없어지는 건 "3코어 노는 구간"의 작은 꼬리라 invoke가 쓸 코어를 못 늘림 → ~0.
- 병목 = **invoke 지연 그 자체**. 남는 15%는 invoke가 못 쓰는 단일스레드 유휴.

### 모델 교체 없이 올리는 법 (효과 순)
1. **NPU/DSP 델리게이트 (Qualcomm Hexagon HTP · QNN/LiteRT)** — 유일한 큰 레버.
   CPU가 dotprod 없어 INT8에 불리 → INT8 전용 하드웨어로 오프로드하면 크게 빨라지고 CPU도 풀림.
   **다음 세션 착수 지점**: 델리게이트 가능 여부 확인 (`libQnn*`/Hexagon 라이브러리, `ai_edge_litert`
   델리게이트 API, AI Hub QNN 컴파일 모델 필요 여부).
2. Adreno GPU 델리게이트 — INT8엔 애매(FP16 선호).
3. 클럭/거버너 — 이미 최대, 효과 없음.
4. 발열 관리 — soak에서 클럭 유지용(부스트 아님).
5. 스레드/파이프라인(draw·encode를 다음 invoke와 겹침) — 소폭 ~10%, 복잡도↑.

> 모델 교체(Thunder→Lightning)는 사용자 지시로 **제외**.

### 관련 산출물
- 승인된 계획 파일 `C:\Users\A\.claude\plans\composed-churning-truffle.md`
  (스트리밍 온/오프 게이팅) — **측정 결과 실익 ~0으로 사실상 폐기 권고.**

---

## 5. PTZ 추적 / 관성(coast) — 이번 세션엔 코드 변경 없음

- 코드: `src/ptz_controller.py`(`update` 326행, `_recover_yaw` 275행), `src/pose_utils.py`(`_target`),
  `src/st3215_bus.py`(서보). 알고리즘 문서: [`2026-07-19_02`](2026-07-19_02_ptz_time_based_control_and_loss_recovery.md).
- **구조도 아티팩트**(mermaid): https://claude.ai/code/artifact/88ddcc5f-215f-4031-b3f3-1a8470d2c277
- 논의된 개선안 (미착수):
  - 관성 "등속" 전환 검토 → **기각 권고**(overshoot↑·FPS의존↑·급정거). 감쇠 유지가 맞음.
  - 일관성 원하면: `coast_frames`→시간 기준, `coast_fov_deg` 실측 보정, 관성 거리 하드캡. 감쇠는 유지.
- 코드 vs 문서 불일치(참고): `2026-07-19_02` 요약 블록의 "10프레임/0.8"은 stale, **실제 15/0.9**.

---

## 6. 다음 세션 착수 후보 (우선순위 제안)

1. **NPU 델리게이트 가능성 조사** — 정확도 안 버리고 FPS 올리는 정공법. §4 착수 지점 참고.
2. **웹 시안 확정** — 5종 중 선택 → 나머지 정리 + `web/DESIGN.md` 갱신.
3. 실기 UX 다듬기 — 카메라 앞에서 각 시안 실제 동작 확인(추적·카운트·PTZ 조작·PIN).
4. (선택) PTZ 일관성 튜닝 — coast 시간 기준화 + fov 보정.

---

## 6-1. 세션 막판 코드 변경 — 영상 오버레이 텍스트 제거 (미검증)

- `src/main.py` 그리기 블록에서 **FPS/각도/REPS/PTZ 글자 오버레이(`putText`) 전부 제거**.
  스켈레톤(`draw_pose`)은 유지. 이유: 그 수치는 웹 UI가 stats.json으로 이미 표시 → 중복.
- FPS 계산·`ptz_snap`은 stats.json/로그에 쓰이므로 남겨둠. 로컬 `py_compile` 통과.
- **로컬 + 디바이스(`~/health_care_bot/src/main.py`) 둘 다 반영 완료.** 컨테이너는 정지 상태라
  **다음 `docker run` 때 적용**된다.
- ⚠️ **실기 미검증** — 다음 세션에 앱 띄워 영상에 글자 없이 골격만 나오는지 + FPS 변화(putText
  제거分, 아마 소폭) 확인 필요.

## 6-2. 연산 집중 모드 — `--idle-skip-draw` (opt-in, 기본 OFF)

- `main.py`에 플래그 추가 + `http_server.py`에 하위호환 변경(`update_live_state(..., encode=)`,
  `viewer_count()`). **플래그 없으면 기존과 100% 동일**(항상 그리기+인코딩).
- `--idle-skip-draw` 주면: **스트림 뷰어 0명일 때 그리기+인코딩을 통째로 skip**(stats.json 숫자는 계속).
  무영상 시안 CORE(= `/stream.mjpg` 안 엶)로만 보면 로봇이 인코딩 없이 추론에 집중.
  영상 시안(CALM/PULSE/…)을 열면 viewer_count>0 → 정상적으로 그리고 인코딩.
- 실행:
  - 기존(비게이팅): `... --serve 8080`
  - 게이팅: `... --serve 8080 --idle-skip-draw`
- ✅ **실기 검증됨(2026-07-21)** — 게이팅(뷰어0·인코딩skip) FPS **~11.44 (11.2~11.6, 안정적)**
  vs 비게이팅 ~11.34. **이득 ~0.1~0.3 fps + 변동 감소(안정화)** — 예측한 "소폭"과 일치.
  천장 ~11.4는 invoke(추론) 바운드 그대로. 정확도 손해 0, 기본 동작 보존.
- 새 웹 시안 **CORE** 추가(무영상, 스쿼트+장치 수치). 시안 총 6종.

## 7. 주의사항 요약
- 디바이스 컨테이너 **현재 실행 중** — 안 쓰면 `docker stop health-care-bot`.
- 카메라 노드·USB 인식은 **부팅마다 확인**(§3).
- 운영자 PIN `1234` (`src/app_state.py`).
- 로컬 미리보기: `cd web && npm run preview -- --host` → `http://localhost:4173/app/?demo=1&ui=aurora`.
- 커밋은 이번 세션에 안 함. (프로젝트 관례: 커밋 전 히스토리 먼저.)

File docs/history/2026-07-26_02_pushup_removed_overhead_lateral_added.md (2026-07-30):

# 2026-07-26 — 푸시업 제거 + 숄더프레스·레터럴레이즈 추가 (정면 선택식)

## 시점

2026-07-26. [`2026-07-26_01`](2026-07-26_01_apple_design_ui_live_and_8080_unify.md)에서 애플 UI를
:8080/app으로 통일한 뒤. 사용자가 "푸시업은 정면/사선에서 애매하다"고 지적 → 종목 개편.

## 왜

**푸시업은 2D 포즈에 부적합.** 팔이 카메라 앞뒤(depth 방향)로 굽고, 몸 방향
자동분류(세로=squat/가로=pushup)가 사선·정면 자세를 오분류한다. → 푸시업을
빼고, **정면을 보고 서서 이미지 평면 안에서 움직이는** 상체 종목으로 교체.

## 무엇을

- **삭제**: 푸시업 (파이프라인·UI·mode에서). 자동 몸방향 분류(select_counter의
  orientation 분기)도 제거 — 전부 정면 종목이라 **모드는 웹 UI에서 명시 선택**.
- **추가**: 숄더프레스(overhead) + 사이드 레터럴 레이즈(lateral).
- 두 종목 모두 **어깨 올림 각도 하나**로 카운트: `shoulder_elev_angle` =
  elbow-shoulder-hip. 팔 내림≈10~20°, 옆 수평(레터럴)≈90°, 머리 위(프레스)≈160~170°.

## 구현 (파일별)

- `src/angles.py`: `shoulder_elev_angle(kp, side)` 추가 (elbow-shoulder-hip). `elbow_angle`는
  미사용으로 남김(무해).
- `src/exercise_counter.py`: `PushupCounter` 자리에 `OverheadPressCounter`(down<60, up>140),
  `LateralRaiseCounter`(down<35, up>80) 추가. 기존 `RepCounter` 히스테리시스+dwell 그대로 재사용.
  (RepCounter 상태 의미: 팔 내림=DOWN, 팔 올림=UP → 올릴 때 rep 카운트.)
- `src/main.py`: import 교체, `_HIGHLIGHT_ARM`(어깨·팔꿈치·손목), `select_counter(mode, squat_c,
  overhead_c, lateral_c)` — orientation 분기 제거하고 mode로만 선택, `compute_angle`에
  overhead/lateral 분기, 카운터 3개 생성, `--mode {squat,overhead,lateral}`(기본 squat),
  임계 플래그 `--overhead-*`/`--lateral-*`, stats에 `squat`/`overhead`/`lateral` 스냅샷.
- `src/app_state.py`: `set_mode` 유효값 `(squat,overhead,lateral)`, 세션 기본 mode `squat`,
  `session_finish(snaps, avg_fps)`로 일반화(reps/best_deg dict).
- `src/http_server.py`: `init_app`에 overhead_c/lateral_c, 세션 start/reset/finish에서 3개 리셋·스냅샷.
- `docker/run.sh`: `--mode auto` → `--mode squat` (아래 함정 참고).
- **프론트 `web/dist/index.html`(=애플 페이지)**: 세그먼트 3버튼(스쿼트/숄더프레스/레터럴),
  reps는 활성 모드 카운터(`d[mode].reps`)에서, 피드백 종목별 분기, 모드는 실제
  `app.session.mode` 반영. 소스: `design_demos/live_apple-design.html`.

## 함정 (재발 방지)

**argparse `choices`를 바꾸면 `docker/run.sh`의 하드코딩 인자도 같이 고쳐야 한다.**
`--mode`에서 `auto`를 없앴는데 run.sh가 `--mode auto`를 넘겨 컨테이너가 즉시 종료됐다
(`invalid choice: 'auto'`). `--rm`이라 `docker logs`엔 안 남아 `run.sh > /tmp/hcb_run.log 2>&1`로
캡처해서 원인 확인. → run.sh를 `--mode squat`로 수정.

## 검증

- 컨테이너 정상 기동(fps ~11, camera video2 자동).
- `stats.json` 카운터 키 = `squat`/`overhead`/`lateral` (pushup 없음).
- 제어권(hcb-demo/PIN 1234) 잡고 `/api/mode` 전환 실측:
  overhead(thr 60/140) · lateral(thr 35/80) · squat(thr 100/140) — `exercise_active`가 즉시 추종.
- `/app`에 3버튼 노출, pushup 없음. PC 접속 확인.

## 남은 것 (실제 측정 필요)

임계값은 **합리적 기본값**일 뿐 스쿼트처럼 실제 사람으로 튜닝 필요:
- overhead down<60/up>140, lateral down<35/up>80 — 실기에서 rep 누락/중복 확인 후 조정.
- 레터럴은 팔을 완전히 편 상태(팔꿈치 안 굽힘)가 각도가 깔끔. 굽히면 elbow가 hip 쪽으로 와 각도 왜곡 가능.
- 카운트가 정면 기준이라 사용자가 카메라를 정면으로 보고 서야 정확.

## 관련

- 실행: `cd ~/health_care_bot && bash docker/run.sh` → `http://192.168.0.45:8080/app`
- 이전: [`2026-07-26_01`](2026-07-26_01_apple_design_ui_live_and_8080_unify.md)

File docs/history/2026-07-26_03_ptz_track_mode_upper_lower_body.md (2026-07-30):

# 2026-07-26 — PTZ 추적을 종목별 상체/하체로 분리

## 시점

2026-07-26. [`2026-07-26_02`](2026-07-26_02_pushup_removed_overhead_lateral_added.md)에서
숄더프레스·레터럴을 추가한 직후. 사용자 지적: "모드별로 추적이 달라져야 한다 —
상반신/하반신."

## 왜

PTZ 컨트롤러가 **항상 무릎 우선**(무릎중점→엉덩이→몸통)으로 추적하고
`pitch_target_y=0.62`(무릎을 화면 하단)로 프레이밍한다. 스쿼트엔 맞지만
**상체 운동(숄더프레스/레터럴)은 팔이 머리 위로 올라가므로 무릎을 추적하면
머리 위 팔이 프레임 밖으로 잘린다.** 종목에 따라 추적 타깃·프레이밍을 바꿔야 한다.

## 무엇을

`PTZController`에 `track_mode`("lower"|"upper")를 추가하고, main.py가 매 프레임
운동 종목에 맞춰 `set_track_mode(exercise)`로 넘긴다.

- **lower (스쿼트)**: 무릎 중점 추적, `pitch_target_y=0.62`, 넓은 데드존(0.20).
  기존과 100% 동일 (track_mode 기본값 "lower").
- **upper (overhead/lateral)**: **어깨 중점 추적**, `pitch_target_y_upper=0.64`
  (어깨를 화면 하단쪽에 둬 **머리 위 든 팔 공간 확보**), 좁은 데드존(0.15,
  어깨는 상하로 거의 안 흔들림). 무릎 밴드 판정·양무릎 속도배율은 하체 모드에서만.

## 구현 (파일별)

- `src/pose_utils.py`: `shoulder_center_normalized()` 추가 (`_mean_center` 재사용).
- `src/ptz_controller.py`:
  - 필드 `pitch_target_y_upper=0.64`, `pitch_deadzone_upper=0.15`, `track_mode="lower"`.
  - `set_track_mode(exercise_or_mode)`: overhead/lateral/'upper' → "upper", 그 외 "lower".
  - `_target()`: upper면 어깨중점→엉덩이→몸통, lower면 무릎중점→엉덩이→몸통.
  - `update()`: 모드별 `pt_y`/`pdz` 적용, `both_knees`는 lower 모드에서만 계산
    (upper면 양무릎 속도배율·무릎밴드 판정 자동 제외).
- `src/main.py`: `ptz.update()` 직전에 `ptz.set_track_mode(exercise)` 호출.

## 검증

- 컨테이너 정상 기동(fps ~11, camera video2), 크래시 없음.
- `/api/mode` 전환 시 `exercise_active` 즉시 추종 확인.
- **주의**: 무인 상태 자동 테스트에선 `ptz.target_norm`이 세 모드 모두 비슷하게
  나왔다 — 사람이 없으면 `_target`이 None이라 추적점이 갱신되지 않기 때문.
  **상체/하체 프레이밍 차이는 실제 사람이 서야 검증된다.**

## 남은 것 (실제 측정 필요)

- 사람이 서서 **숄더프레스/레터럴 시 머리 위 팔이 프레임 안에 남는지** 확인.
  잘리면 `pitch_target_y_upper`를 키워(예: 0.68~0.72) 어깨를 더 아래로 내린다.
- 레터럴은 팔이 옆으로 넓게 벌어져 **좌우 프레임에 걸릴 수 있음**(줌 없음) —
  사람이 충분히 뒤에 서야 함. 코드로는 해결 불가, 세팅으로 대응.
- 스쿼트 동작이 종전과 동일한지 회귀 확인.

## 관련

- 실행: `cd ~/health_care_bot && bash docker/run.sh` → `http://192.168.0.45:8080/app`
- 이전: [`2026-07-26_02`](2026-07-26_02_pushup_removed_overhead_lateral_added.md)

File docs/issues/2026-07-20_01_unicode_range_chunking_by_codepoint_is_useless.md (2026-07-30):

# 한글 웹폰트를 코드포인트 순으로 쪼개면 아무 효과가 없다

## 증상

Pretendard 2.0MB를 줄이려고 `unicode-range`로 44조각(조각당 256음절)을
만들었다. 브라우저는 "실제로 그리는 글자가 든 조각만" 받아가므로 크게
줄 것이라 기대했다.

실측해보니 **텍스트가 많은 화면이 37조각을 요청**했다. 거의 전부를
받은 셈이라 쪼갠 의미가 없었다.

```
almanac  woff2 요청: base kr-00 kr-01 kr-02 kr-04 kr-05 kr-06 kr-07 kr-08
                     kr-09 kr-11 kr-12 kr-13 kr-14 kr-15 kr-16 kr-17 kr-20
                     kr-21 kr-22 kr-25 kr-26 kr-27 kr-28 kr-29 kr-32 kr-33
                     kr-34 kr-35 kr-36 kr-38 kr-39 kr-40 kr-41 kr-42 ...
```

## 원인

한글 음절 11,172자를 코드포인트(`U+AC00`~`U+D7A3`) **순서대로** 자르면,
조각 하나에 "가·각·갂·갃…" 같이 **초성이 같은 글자들만** 들어간다.

그런데 실제 문장은 초성이 골고루 흩어져 있다. "무릎과 발끝이 안정적입니다"
한 문장만 해도 ㅁ·ㄹ·ㄲ·ㅂ·ㄹ·ㄲ·ㅇ·ㅈ·ㅈ·ㅇ·ㄴ·ㄷ — 12자에 조각이
10개쯤 걸린다. 화면 하나만 그려도 대부분의 조각을 건드리게 된다.

즉 **코드포인트 순서와 사용 빈도 사이에 아무 상관이 없다.**

## 해결

빈도순으로 재배치한다. 소스에 실제로 등장하는 글자만 모아
**우선 조각(`kr-core.woff2`)을 만들고 맨 앞에 선언**한다.

```python
def used_hangul() -> set[int]:
    """src/ 안 문구에 실제로 등장하는 한글 음절."""
    out = set()
    for path in (ROOT / "src").rglob("*"):
        if path.suffix not in {".ts", ".tsx", ".css", ".html"}:
            continue
        for ch in path.read_text(encoding="utf-8"):
            if HANGUL_START <= ord(ch) <= HANGUL_END:
                out.add(ord(ch))
    return out
```

나머지 음절은 코드포인트 순 조각으로 뒤에 남긴다. 이때 **우선 조각에
든 글자는 뒤쪽 조각에서 빼야 한다** — 같은 코드포인트를 두 face가 함께
주장하면 어느 쪽이 이길지 브라우저 구현에 맡기게 된다.

## 결과

| | 이전 | 이후 |
|---|---|---|
| woff2 요청 수 | 37 | 3~4 |
| 폰트 전송량 | ~1.9 MB | 226~346 KB |

## 왜 "쓰는 글자만 남기기"로 안 갔나

가장 작아지지만, 한국어 문구를 한 글자라도 바꾸면 두부(□)가 뜬다.
서버가 보내는 문자열까지 생각하면 더 위험하다.

우선 조각 + 안전망 조각 구조는 **모든 글자가 어딘가에는 있으므로
두부가 원천적으로 불가능**하면서, 평소에는 우선 조각 하나로 끝난다.

## 재발 방지

한국어 문구를 크게 바꿨거나 폰트를 추가했으면 다시 돌린다:

```bash
cd web && python scripts/subset_pretendard.py
```

돌리지 않아도 안전망 조각이 받쳐주므로 화면이 깨지지는 않는다.
다만 요청 수가 늘어나므로 주기적으로 갱신하는 게 좋다.

## 관련

- [`2026-07-20_01_web_redesign_four_variants`](../history/2026-07-20_01_web_redesign_four_variants.md)
- `web/scripts/subset_pretendard.py`

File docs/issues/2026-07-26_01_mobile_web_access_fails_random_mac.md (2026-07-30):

# 폰으로 로봇 웹앱 접속 안 됨 — 폰 "랜덤 MAC"이 원인 (ERR_ADDRESS_UNREACHABLE)

## 증상

사용자 폰에서 `http://192.168.0.45:8080/app` 접속 시 크롬 에러:

```
사이트에 연결할 수 없음
http://192.168.0.45:8080/app 에 연결할 수 없습니다.
ERR_ADDRESS_UNREACHABLE
```

- **다른 사람 폰은 같은 네트워크면 정상 접속**된다. 사용자 폰만 안 됨.
- 같은 날 오전(11:00경)에는 **이 폰도 됐었다**(`/tmp/demo_http.log`의 `192.168.0.44` 200 기록 확인). 도중부터 안 됨.
- 폰 Wi-Fi 설정상 IP는 `192.168.0.44`로 보였다(디바이스는 `192.168.0.45`, 같은 /24).

## 원인

**폰의 "임의(랜덤)/비공개 Wi-Fi MAC 주소" 기능.** 랜덤 MAC이 켜져 있으면 공유기가 그 폰을 매번 다른 기기로 인식해 **다른 서브넷 배정 또는 격리** 처리를 하고, 그 결과 폰이 `192.168.0.0/24`로 가는 **경로 자체를 잃는다.**

**에러 메시지가 핵심 단서였다:**

| 크롬 에러 | 의미 | 원인 방향 |
|---|---|---|
| **`ERR_ADDRESS_UNREACHABLE`** | 대상 IP로 가는 **경로 없음** | 폰이 그 서브넷 밖(랜덤MAC / 셀룰러 폴백 / 다른 SSID) |
| `ERR_CONNECTION_TIMED_OUT` | 경로는 있는데 응답 없음 | AP 클라이언트 격리 / 방화벽 |
| `ERR_CONNECTION_REFUSED` | 닿았는데 포트 닫힘 | 서버 미기동 / 포트 오류 |

즉 `ADDRESS_UNREACHABLE`는 **서버·네트워크 문제가 아니라 폰이 해당 LAN에 실제로 안 붙어 있다**는 신호다.

## 진단 과정 (오인 방지)

디바이스·네트워크는 정상임을 먼저 배제했다:

- `:8080`(run.sh)·`:8777`(정적) 둘 다 `ss -tlnH`에서 `0.0.0.0` 바인딩 확인.
- **AP 클라이언트 격리 아님** — PC의 Wi-Fi 인터페이스(`192.168.0.9`)에서 소스 바인딩해 `192.168.0.45:8080/8777`로 TCP 접속 성공(무선→무선 통함).
- 접속 로그(`/tmp/demo_http.log`)에 폰 요청이 **도달했는지** 확인 → 특정 시점 이후 도달 안 함(경로 소실과 일치).

## 영향

- 데모 중 **특정 폰만 접속 불가** → "네트워크 죽었나 / 서버 문제인가"로 오인해 엉뚱한 곳(서버·포트·코드)을 헤매게 된다. 실제로 이번에도 웹 버전 롤백까지 시도했으나 원인은 폰이었다.

## 해결

폰의 그 Wi-Fi 네트워크 설정에서 **"비공개/임의 MAC 주소" → "기기(디바이스) MAC 사용"** 으로 바꾸고 재접속 → 정상 서브넷에 붙어 즉시 해결.

## 재발 방지

- **에러 메시지로 먼저 원인을 가른다** (위 표). `ADDRESS_UNREACHABLE`면 서버가 아니라 **폰의 네트워크 소속**부터 본다.
- 폰 쪽 진단 순서: ① 모바일 데이터 OFF(로봇 Wi-Fi에 인터넷 없으면 LTE로 새어나감) → ② 다른 폰과 **정확히 같은 SSID**(…5G/guest/중계기 아님) → ③ 폰 IP `192.168.0.x` 확인 → ④ Wi-Fi 잊기·재접속("인터넷 없음, 연결 유지?"→유지) → ⑤ **랜덤 MAC OFF** → ⑥ VPN/사설DNS OFF.
- **데모 당일**: 참석자 폰들도 같은 함정 가능 → 접속 안 되는 폰은 "그 네트워크에서 랜덤 MAC 끄기"를 먼저 안내. 가능하면 공유기 쪽에서 랜덤MAC 클라이언트를 정상 서브넷에 넣도록 설정.
- 상세 메모리: `.claude/.../memory/project_hcb_demo_network.md`.

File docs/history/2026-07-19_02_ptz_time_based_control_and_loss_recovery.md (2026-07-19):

# 2026-07-19 — PTZ 제어를 시간 기준으로 전환 + 추적 손실 복구 사다리

## 시점

2026-07-19. UNO Q 실기에서 PTZ 추적을 처음 돌려본 직후
([`2026-07-19_01`](2026-07-19_01_device_code_deploy_synced.md)에서 코드 동기화 완료).

## 사건

실기에서 카메라가 "톡톡" 끊기며 따라오는 현상. 원인이 제어 법칙의 프레임
의존성으로 밝혀져 **각속도(deg/s) 기준으로 전환**하고, 명령 주기와 손실
복구 동작까지 함께 정리.

## 배경 — 왜 PC에선 부드럽고 실기에선 끊겼나

코드는 PC와 디바이스가 md5까지 동일했다. 차이는 **프레임레이트**였다.

| | FPS | 출처 |
|---|---|---|
| 개발 PC | ~29 | [`2026-07-17_03`](2026-07-17_03_ptz_camera_tracking_v1_local_pc.md) |
| UNO Q | ~11 | 이번 실기 로그 실측 |

기존 제어식은 `step = clamp(gain * ex, ±max_step) * scale`을 **매 프레임
누적**했다. 즉 `gain=8.0`, `max_step=4.0`은 "프레임당 도수"였고, 암묵적으로
29 FPS에 튜닝된 값이었다. 11 FPS에서는 같은 시간에 누적되는 프레임이
1/2.6로 줄어 **각속도도 1/2.6**이 됐다.

여기에 두 번째 요인이 겹쳤다. 서보는 569 tick/s ÷ 11.375 tick/deg =
**50 deg/s**로 도는데, 목표각이 밀리는 속도는 최대 29 deg/s였다. **서보가
목표보다 1.7배 빠르니 매번 먼저 도착해서 남는 시간을 멈춰 있었다.**
250ms 주기 기준으로 오차가 클 때도 105ms(주기의 42%), 절반일 땐 178ms(71%)를
정지 상태로 보냈다. 이게 "톡톡"의 정체.

## 변경 1 — 프레임당 → 초당 (각속도)

`ref_fps`를 곱하는 중간 단계를 거쳐 최종적으로 **deg/s를 직접 표현**하도록
정리했다. 제어식에서 프레임레이트 개념이 완전히 사라졌다.

```python
# 전 - "29 FPS에서의 프레임당 도수"라는 간접 단위
gain: float = 8.0
max_step: float = 4.0

# 후 - 각속도 그 자체
gain_deg_per_s: float = 232.0    # 8.0 x 29
max_deg_per_s: float = 116.0     # 4.0 x 29
```

```python
deg_per_s = clamp(gain_deg_per_s * ex, ±max_deg_per_s) * scale
self.pan_deg += yaw_sign * deg_per_s * dt_s
```

`dt_s`는 `max_dt_s=0.15`로 상한을 둔다 — LOST 구간을 건너뛴 직후 dt가 커져
한 번에 튀는 것을 막기 위함. 첫 프레임은 간격을 알 수 없으므로 `dt_s=0`.

**검증** (합성 keypoint, 1초간 yaw 회전량):

| FPS | BEFORE | AFTER | 29 FPS 대비 편차 |
|---|---|---|---|
| 29 (PC) | 25.20 | 25.20 | 0% — 회귀 없음 |
| 20 | 17.10 | 24.79 | 32% -> 1.6% |
| **11 (UNO Q)** | **9.00** | **23.73** | **64% -> 5.8%** |
| 6 | 4.50 | 19.57 | 82% -> 22.3% |

6 FPS의 잔여 편차는 `max_dt_s` 상한이 걸린 것으로 의도된 동작.

## 변경 2 — 명령 쿨다운 250ms -> 80ms

서보가 먼저 도착해 노는 문제를 직접 해소. 11 FPS면 프레임 간격이 91ms라
80ms는 사실상 "매 프레임 전송"이 된다. 1Mbaud에 명령 15바이트라 버스 부하는
무시 가능.

**사용자 체감으로 개선 확인됨** ("아까보다 낫다") — 서보가 먼저 도착해
정지한다는 진단이 맞았음.

## 변경 3 — 추적 손실 복구 사다리 (yaw 전용)

기존에는 미검출이면 `return None`으로 **아무것도 안 했다.** 사람이 빠르게
프레임 밖으로 나가면 카메라가 그 자리에 얼어붙었다.

4단계 사다리를 넣었다. 어느 단계든 **재검출되면 즉시 취소**되고 정상 추적
으로 돌아간다.

```
연속 미검출 3프레임 (단발 깜빡임 무시)
  -> 관성 10프레임 (마지막 yaw 각속도로, 프레임당 0.8 감쇠)
  -> 그 자리에서 1초 대기
  -> 관성 이전 위치로 복귀, 2초 대기
  -> 중앙(180) 복귀 후 정지
```

**관성 방향은 "마지막 yaw 각속도"를 쓴다.** 이게 핵심 안전장치다 — 사람이
중앙에 가만히 있어 카메라가 안 움직이던 중이면 각속도가 0이라 **관성이 아예
안 걸린다.** 검출만 깜빡인 경우의 헛발질이 이 규칙 하나로 걸러진다.

**검증** (11 FPS 시뮬레이션, 서보 없이):

| 시나리오 | 결과 |
|---|---|
| 깜빡임 필터 | miss 1~2 무반응 |
| 관성 | miss 3~12, 총 +10.6도 (감쇠 적용) |
| 1초 후 복귀 | miss 23에서 `BACK` — 관성 이전 위치와 정확히 일치 |
| 2초 후 중앙 | miss 45에서 `CENTER 180.0` |
| 소프트리밋 | 90 <= 180 <= 270 준수 |
| 관성 중 재검출 | stage 즉시 `none`, 상태 전부 초기화 |
| **정지 중 손실** | 각속도 0 -> **관성 0.00도**, 바로 대기 단계로 |

로그 태그: `COAST` / `BACK` / `CENTER`.

## 변경 4 — 관성 근거를 "피사체 속도"로 교체 (실기 피드백 반영)

복구 사다리를 실기에서 돌려본 결과, **빠르게 프레임을 벗어나면 관성이 아예
걸리지 않는** 문제가 보고됐다. 적당한 속도로 나가면 정상 동작.

### 원인 — 데드존 밴드

초기 구현은 관성 방향/속도를 **카메라의 마지막 각속도**(`_last_yaw_vel`)에서
가져왔다. 그런데 이 값은 `yaw_out`일 때만 갱신된다:

```python
yaw_dead = 0.5 - sector_side = 1/3        # 중앙 4/6 밴드
yaw_out = abs(ex) > yaw_dead              # 밴드 밖일 때만 카메라가 움직임
```

**중앙 밴드 안에서는 카메라가 안 움직이므로 각속도가 0이다.** 빠르게 나가면
그 밴드를 한 프레임도 밟지 않고 화면 밖으로 사라질 수 있다 — 11 FPS면 프레임
간격이 91ms라 2~3프레임 만에 중앙에서 화면 밖까지 간다.

시뮬레이션으로 재현 확인:

| 시나리오 | 손실 직전 카메라 각속도 | 관성 |
|---|---|---|
| 느린 이탈 (밴드 밖 체류) | +22.48 deg/s | O |
| **빠른 이탈 (밴드 안에서 사라짐)** | **+0.00** | **X** |
| 빠른 이탈 (밴드 밖 1프레임만) | +11.14 | O (절반) |

사용자가 후보로 지목한 "3프레임 필터"나 "중앙에서 사라졌다는 판정"이 아니라
**데드존 밴드가 원인**이었다.

### 설계 결함 — 카메라 속도는 잘못된 신호였다

"카메라가 얼마나 돌고 있었나"는 "사람이 얼마나 빨리 움직였나"가 아니다.
반대 경우도 문제다 — 카메라가 사람을 잘 따라가고 있으면 화면 속 사람은 거의
정지해 보이므로, 그 상태로 이탈해도 신호가 약하다.

올바른 값은 **사람의 실제 각속도**이고, 두 성분의 합이다:

```
사람의 각속도 = 카메라 각속도 + (화면 내 잔여 이동량 x 화각)
```

`_prev_smooth_x`를 들고 프레임 간 변화량으로 화면 내 피사체 속도를 낸다.
손실 구간을 건너뛴 델타는 시간 간격이 불확실해 버린다.

### 결과

| 시나리오 | 카메라 | 화면 내 | 관성 초기속도 |
|---|---|---|---|
| 느린 이탈 | +22.48 | +0.53/s | +43.47 deg/s |
| **빠른 이탈 (중앙에서)** | 0 | +1.02/s | **+49.00** |
| 초고속 (1프레임) | 0 | +1.32/s | **+63.36** |
| **중앙 정지 손실** | 0 | 0 | **0** (관성 안 걸림) |
| 가장자리 정지 손실 | +23.19 | 0 | +18.62 |

**이탈이 빠를수록 관성이 커진다.** 그리고 제자리 손실에서 관성이 안 걸리는
안전 성질은 그대로 유지됐다 — 두 성분이 모두 0이기 때문.

소프트리밋도 한계에서 밀어붙여 검증했다. yaw 90~270을 넘지 않고(정확히
270.00 / 90.00에서 정지), 관성 속도도 `max_deg_per_s=116`에서 잘린다.
pitch는 복구 사다리가 건드리지 않는다(yaw 전용).

### 현재 튜닝값

| 필드 | 값 | 비고 |
|---|---|---|
| `coast_start_misses` | 3 | 0.27초는 깜빡임으로 무시 |
| `coast_frames` | 15 | 11 FPS에서 1.36초 |
| `coast_decay` | 0.9 | 약 44도 이동 |
| `coast_fov_deg` | 60 | **추정값 — 실측 보정 필요** |

`coast_fov_deg`는 카메라 수평 화각으로, 관성 속도를 직접 결정한다. 정확한
값을 모르므로 60도로 두었다. 보정법: 카메라를 알려진 각도만큼 돌려놓고
피사체가 화면 폭의 몇 %만큼 밀리는지 재면 나온다 (15도 회전에 30% 밀리면
화각 = 15 / 0.30 = 50도).

### 실기 확인 완료 (2026-07-19)

**로봇에서 동작 확인됨 — 잘 따라간다.** 위 튜닝값(`coast_frames=15`,
`coast_decay=0.9`, `coast_fov_deg=60`) 그대로 실사용에 문제가 없었다.

특히 최초 보고였던 **"빠르게 나가면 못 따라온다"가 해소된 것을 확인**했다.
`coast_fov_deg=60`은 여전히 실측이 아닌 추정값이지만 실기에서 충분히 동작하므로,
정밀 보정은 필요해지는 시점으로 미룬다.

## 발견했으나 고치지 않은 것

### 스쿼트 rep 오검출 — `bottom=5도`

첫 실기 스쿼트 측정에서 가짜 rep이 잡혔다.

```
[ 180] L=119 R=180도     <- 좌우 61도 차이. 이미 신뢰 못 할 값
[ 195] L=  ? R=  ?도     <- 검출 실패
[ 210] L=  ? R=  ?도     <- 검출 실패
  * SQUAT REP #1  bottom=5도  (frame 216)
[ 225] L=173 R=175도
```

무릎 각도 5도는 해부학적으로 불가능(실제 한계 30~40도). 원인은 **2D 투영
왜곡** — 다리가 카메라 쪽을 향하면 hip-knee-ankle이 화면상 거의 한 점으로
뭉쳐 각도가 실제보다 훨씬 작게 나온다. 키포인트 오류가 아니라 정상
키포인트의 투영 문제라, `conf >= 0.3` 게이트로는 걸러지지 않는다.

구조적 취약점도 확인: **rep 하나가 단 2개의 유효 샘플로 완성된다.**
`None` 프레임은 상태를 유지한 채 그냥 넘어가므로, 검출이 끊긴 구간을 사이에
두고 "튄 값 1개 + 정상값 1개"만으로 UP->DOWN->UP이 성립한다. `min_dwell_ms=200`은
11 FPS에서 3프레임이면 넘어 제약이 못 된다.

**대응 보류 결정.** 검토한 방안과 기각 사유:

- *해부학적 범위 게이트(30도 미만 버리기)* — 왜곡은 자세에 따라 연속적으로
  생기므로 30도를 잘라도 31도짜리 왜곡값은 통과한다. 증상의 꼬리만 자름
- *좌우 40도 불일치 게이트* — 양쪽이 동시에 잡혀야 비교가 되는데 한쪽만
  잡히는 프레임이 많아, 정작 필요한 상황에 작동하지 않음

두 방안 모두 **검출률을 떨어뜨리면서 근본 원인은 못 잡는다**고 판단. 이미
`?`가 대부분인 상황에서 더 조이면 카운트 자체가 불가능해진다. 사용자 판단으로
현행 유지.

향후 검토할 대안: `DOWN` 구간에 **유효 샘플 N개 이상**을 요구 (검출률을
건드리지 않고 2샘플 rep만 차단), 또는 측면 촬영 전제, 또는 각도 대신 투영에
덜 민감한 지표(엉덩이 높이 변화량 등).

### 관성 지속 시간이 아직 "프레임 수" 기준 (의도적 보류)

추적 제어는 시간(deg/s) 기준으로 바꿨는데, **관성 지속만 `coast_frames`라는
프레임 수로 남아 있다.** 같은 실수를 한 군데에 다시 넣은 셈이다.

결과적으로 FPS가 다르면 관성 지속 시간과 이동 거리가 달라진다:

| | 프레임 간격 | 15프레임 지속시간 | 상대 이동거리 |
|---|---|---|---|
| UNO Q (11 FPS) | 91ms | 1.36초 | 1.00 |
| PC (29 FPS) | 34ms | 0.52초 | 0.38 |

**PC에서 디버깅하면 관성이 2.6배 짧게 보인다.** 지금은 UNO Q에서만 돌리므로
실사용에는 영향이 없어 보류했으나, PC와 실기 동작을 비교할 때 혼동의 원인이
될 수 있다.

고치려면 `coast_frames: int` -> `coast_duration_s: float`로 바꾸고, 감쇠도
프레임당이 아니라 시간당(`decay^(dt/기준dt)`)으로 환산해야 한다.

### 감쇠가 지배적이라 coast_frames는 거의 효과가 없다

관련해서 측정으로 드러난 것. `coast_decay=0.8`이면 프레임을 늘려도 이동
거리가 거의 안 늘어난다 — 뒤쪽 프레임의 속도가 이미 0에 가깝기 때문.

| coast_frames | 이동거리 | | coast_decay | 이동거리 |
|---|---|---|---|---|
| 10 | 24.85도 | | 0.80 | 26.86도 |
| 15 | 26.86도 (+8%) | | 0.85 | 33.88도 (+26%) |
| 30 | 27.81도 (+12%) | | 0.90 | 44.22도 (+65%) |

**관성 거리를 조절하려면 `coast_frames`가 아니라 `coast_decay`를 만져야 한다.**
`coast_frames`는 "얼마나 오래 꼬리를 끄는가"만 결정한다.

### 검출 불안정 — 실질적 병목

로그에 `ptz=lost`가 **90프레임(약 8초) 연속**으로 나오는 구간이 있었다. 사람이
그 자리에 있는데 못 잡은 것. 무릎 각도도 대부분 `?`(hip/knee/ankle 3점 중
하나 이상이 conf 미달). **스쿼트 검증의 실질적 병목은 제어가 아니라 검출**이다.
거리/화각/조명 중 무엇이 원인인지는 `/app` 화면으로 프레이밍을 봐야 갈린다.

## 문서 오류 — 아직 미수정

이번 실기에서 기존 문서 두 곳이 틀렸음이 드러났다. **아직 안 고쳤다.**

1. **"Venus가 video0·1을 선점하니 video2 이상이 진짜 카메라"** — 이번 부팅에선
   **정반대**였다. USB 카메라가 `/dev/video0`·`video1`, Venus가 `video2`·`video3`.
   즉 노드 번호는 부팅마다 바뀌므로 **매번 `v4l2-ctl --list-devices`로 확인**해야
   하고, "video2 이상"이라는 규칙 자체가 틀렸다.
   (HANDOFF §5-2, `docker/run.sh` 주석)
2. **`SERIAL_DEV` 기본값 `/dev/ttyUSB0`** — 실제로는 CH343이 **`/dev/ttyACM0`**로
   잡힌다. 기본값 그대로 두면 PTZ가 조용히 disabled로 떨어진다.
   (HANDOFF §5-2, `docker/run.sh`)

## 다음 단계

1. 복구 사다리 실기 체감 확인 (`COAST`/`BACK`/`CENTER` 로그)
2. 검출 안정성 — `/app`으로 프레이밍 확인, 발목까지 들어오는 거리 찾기
3. 위 문서 오류 2건 수정
4. `health_care_bot`이 git 저장소가 아님 — 버전 관리 도입 검토

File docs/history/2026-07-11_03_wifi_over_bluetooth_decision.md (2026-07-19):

# 2026-07-11 — 네트워크 의존성 완화안으로 Bluetooth 검토 후 기각

## 시점

2026-07-11

## 사건

사용자가 "같은 네트워크에 있어야 한다"를 웹앱의 최대 단점으로 지목하며
Bluetooth 기반 앱 전환 가능성을 문의. 검토 후 WiFi/HTTP 아키텍처 유지로
결론.

## 배경

Health Care Bot Live는 로컬 LAN 전용 HTTP 서버 위에서 동작한다
(`web/ARCHITECTURE.md` §3, §8). IP가 바뀌거나 시연장 WiFi가 불안정하면
QR 접속이 깨질 수 있다는 게 알려진 제약이었고, 이를 Bluetooth로 우회할 수
있는지가 논점이었다.

## 결과

기각. 근거 3가지:

1. **영상 스트리밍 대역폭 부족** — 이 앱의 핵심 기능은 라이브 카메라
   (MJPEG)인데 BLE는 이를 감당할 대역폭이 안 되고, Bluetooth Classic(SPP)은
   그나마 낫지만 브라우저 API로 접근 불가 → 네이티브 앱 필요 → PWA로
   결정한 이유(`web/ARCHITECTURE.md` §2)와 정면 충돌.
2. **iOS Safari가 Web Bluetooth 미지원** — "QR 스캔 후 설치 없이 3초 접속"
   이라는 핵심 목표(`APP_PLAN.md` §1, §14)가 아이폰 사용자 전원에게서
   깨진다.
3. **원래 병목을 안 풀어준다** — PTZ 명령 같은 저대역폭 채널만 Bluetooth로
   빼도 영상은 어차피 WiFi가 필요해, 사용자가 실제로 겪는 "네트워크
   의존성" 문제 자체는 해결되지 않는다.

네트워크 의존성 문제는 기존에 논의된 mDNS(`healthbot.local`) 또는 UNO Q
자체 핫스팟(hostapd) 쪽으로 대응하는 방향을 재확인 — 둘 다 `APP_PLAN.md`
§5에 설계는 있으나 아직 코드 미구현 상태.

## 다음 단계

시연 네트워크 환경이 확정되면 mDNS 또는 핫스팟 중 하나를 실제로 구현.

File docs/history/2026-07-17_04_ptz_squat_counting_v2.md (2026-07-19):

# 2026-07-17 — PTZ 추적 + 스쿼트 카운팅 통합 v2 확정 + 백업

## 시점

2026-07-17 (PTZ 추적 v1
[2026-07-17_03](2026-07-17_03_ptz_camera_tracking_v1_local_pc.md) 이어서)

## 사건

PC 로컬 PTZ 추적 스크립트(`scripts/ptz_camera_track.py`)에 **스쿼트 rep 카운팅**을
붙여 "추적 + 카운팅"이 한 루프에서 동시에 도는 v2를 완성하고 백업했다.

백업: `scripts/ptz_camera_track_v2_ptz_squat.py` (byte-identical)

## 배경

- 카운팅 로직을 새로 짜지 않고 **본 라인의 검증된 모듈을 그대로 재사용**:
  `src/exercise_counter.py::SquatCounter` (UP↔DOWN 히스테리시스 100°↔140°,
  `min_dwell_ms=200` 지터 방지) + `src/angles.py::knee_angle`(hip-knee-ankle) /
  `pick_angle`(좌우 선택). `src/main.py`가 쓰는 것과 동일한 패턴.
- 추적 목표점(무릎 중점)과 카운팅 입력(무릎 각도)이 같은 무릎 키포인트를 쓰므로
  자연스럽게 한 파이프라인에서 처리됨.

## 결과 — v2 추가분 (v1 기능은 그대로 유지)

- 매 프레임 무릎 각도 계산 → `SquatCounter.update(angle, now_ms)` → rep 검출
- 화면 우상단 `SQUAT <n> [UP|DOWN]` + `knee <deg>deg`, rep 완료 순간 노란색 강조
- 콘솔 `★ SQUAT REP #n bottom=<deg>deg (frame N)`, 종료 시 총 reps/deepest 요약
- 키: `q` 종료, **`r` 카운트 리셋**
- 옵션: `--squat-down-th`(100) / `--squat-up-th`(140) / `--min-dwell-ms`(200) /
  `--side {left,right,avg,better}` / `--no-count`(카운팅 끄기)

검증: 합성 각도 시퀀스(하강→상승 2회)로 REP 2회·bottom 85°/80°·deepest 80° 정상
검출 확인. 스크립트 전체 헤드리스 스모크 테스트 통과(크래시 없음).

## 주의 / 실측 조건

- **무릎 각도는 hip·knee·ankle 3점이 모두 conf 임계 이상이어야 계산됨** →
  카운팅하려면 최소 발목까지 프레임에 들어오는 거리에서 촬영해야 함.
- 카메라 인덱스는 USB 재연결 때마다 뒤바뀔 수 있음 (이번에 내장 웹캠↔짐벌
  카메라가 0↔1로 스왑됨). 헷갈리면 각 인덱스에서 한 장 캡처해 확인할 것.
- 같은 시점에 서보가 ID 1~5 전부 무응답인 상태가 발생 → COM 포트/ID 문제가 아니라
  **서보 외부 전원(6~12.6V)·버스 케이블** 쪽 이슈로 좁혀짐(포트는 정상 오픈).

## 다음 단계

- pitch 세로 프레이밍 튜닝(목표 y 0.5 → 0.65~0.7)은 v1부터 이월된 미해결 항목.
- 서보 전원 복구 후 실제 스쿼트로 카운팅 실측 검증(현재는 합성 검증까지만).
- 본 파이프라인(`src/main.py`) 통합 여부는 미결정 — 현재는 독립 테스트 스크립트.

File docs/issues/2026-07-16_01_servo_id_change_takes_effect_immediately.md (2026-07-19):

# ST3215 ID 변경이 "실패" 로그를 남기고도 실제로는 즉시 반영됨

## 증상

`set-id` 명령(`unlock LOCK → write ID → lock LOCK`, 모두 기존 ID로
전송)을 실행했더니 `[FAIL] 응답 헤더 없음/깨짐: b''` 에러로 실패
처리됐다. 그런데 그 이후 같은 ID로 재시도(`ping`)해도 계속 응답이
없었고, 새 ID로 `ping`을 날려보니 **정상 응답**이 왔다 — 즉 명령은
"실패"로 보고됐지만 ID 변경 자체는 이미 성공한 상태였다.

## 원인

일부 Feetech 레퍼런스(예: 서드파티 Python SDK의 `set_motor_id` 경고
문구, "전원 재투입 후 반영됨")는 ID 변경이 **전원 재투입 전까지는
적용되지 않는다**고 가정하고, unlock/write/lock 세 패킷을 전부
**기존 ID**로 보내도록 짜여 있다. 하지만 이번에 쓴 실제 서보 펌웨어는
`ID` 레지스터(addr 5)에 새 값을 쓰는 즉시 자신의 통신 ID를 전환한다.
그 결과:

1. `write_byte(old_id, ADDR_ID, new_id)` 패킷을 받는 순간 서보가
   이미 `new_id`로 전환됨.
2. 바로 다음에 보낸 `write_byte(old_id, ADDR_LOCK, 1)`(lock) 패킷은
   이제 아무도 응답하지 않는 `old_id`로 전송된 것이 되어 타임아웃 →
   `b''` 빈 응답 → 스크립트가 실패로 보고.
3. 그러나 ID 전환 자체(1~2단계)는 이미 끝난 뒤였으므로, 실제로는
   EEPROM 쓰기가 (lock 재설정만 빠진 채) 성공한 상태.

## 해결

새 ID로 재시도 `ping`을 날려서 이미 전환됐는지부터 확인하는 방식으로
대응 — 실제로 `--id 2 ping`이 정상 응답해서 변경이 이미 끝났음을
확인했다. `set-id` 서브커맨드 자체는 코드 수정 없이 그대로 둠 (lock
스텝이 새 ID로 실패하는 것 자체는 무해 — EEPROM 잠금이 안 걸린
상태로 남을 뿐, 다음 세션에서 `unlock`부터 다시 하면 잠글 수 있음).

## 재발 방지

- ST3215(적어도 이번에 쓴 개체/펌웨어 버전)는 **ID 변경이 즉시
  반영**된다 — "전원 재투입 필요"라는 일반적인 SDK 경고 문구를
  맹신하지 말 것. `set-id` 실행 후 실패 로그가 떠도 곧바로 새 ID로
  `ping`해서 실제 상태부터 확인한다.
- 여러 서보를 동시에 체인에 물린 채로 ID 변경을 시도하면, 위 즉시전환
  특성 때문에 ID 충돌/응답 없음이 더 헷갈리게 나타날 수 있다 — 반드시
  서보를 **한 번에 하나씩만** 어댑터에 연결한 상태에서 ID를 미리
  나눠 기록한다(`ptz/sketch/health_care_ptz.ino` 헤더 주석과 동일한
  권고).
- `set-id` 명령의 마지막 `lock` 스텝이 실패로 뜨는 것은 사실상
  "ID가 이미 바뀌어서 옛 주소가 응답 안 하는" 정상적 부작용이지,
  EEPROM 쓰기 자체의 실패를 의미하지 않는다.

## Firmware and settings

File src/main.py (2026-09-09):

#!/usr/bin/env python3
"""헬스케어 봇 통합 진입점 - 1 process, 1 컨테이너.

흐름:
  카메라 → MoveNet Thunder INT8 → 17 keypoint
      ├─ 각도 계산 (knee / elbow)
      ├─ rep counter (mode에 따라 squat / overhead / lateral - 자동 분류 없음)
      ├─ PTZ controller (추적점: 스쿼트는 무릎 가중 중심, 그 외 상반신 중심 → 프레임-아웃 → Arduino 시리얼 명령)
      └─ HTTP serve (MJPEG + stats.json)
"""
import argparse
import os
import sys
import threading
import time
from collections import deque
from pathlib import Path

import numpy as np
import cv2

# 같은 폴더 모듈
sys.path.insert(0, str(Path(__file__).resolve().parent))
from pose_utils import KP, letterbox_square, unletterbox_kp, person_center_normalized, person_center_weighted, draw_pose
from angles import knee_angle, shoulder_elev_angle, pick_angle, body_orientation
from exercise_counter import SquatCounter, OverheadPressCounter, LateralRaiseCounter
from ptz_controller import PTZController
from http_server import update_live_state, start_server, init_app, viewer_count
import app_state
import guard_capture

try:
    from ai_edge_litert import interpreter as tflite
    RUNTIME = "ai_edge_litert"
except ImportError:
    try:
        import tflite_runtime.interpreter as tflite
        RUNTIME = "tflite_runtime"
    except ImportError:
        import tensorflow.lite as tflite
        RUNTIME = "tensorflow.lite"


# === 자세별 좌/우 keypoint 강조 인덱스 (draw용) ===
_HIGHLIGHT_SQUAT = [KP["left_knee"], KP["right_knee"]]
_HIGHLIGHT_ARM = [KP["left_elbow"], KP["right_elbow"], KP["left_wrist"], KP["right_wrist"]]


def get_rss_mb():
    try:
        with open('/proc/self/status') as f:
            for line in f:
                if line.startswith('VmRSS:'):
                    return int(line.split()[1]) / 1024.0
    except Exception:
        return None
    return None


def get_cpu_temp_c():
    """SoC 온도 (millidegree C → C). Windows/온도 노드 없는 환경에서는 None."""
    try:
        with open('/sys/class/thermal/thermal_zone0/temp') as f:
            return int(f.read().strip()) / 1000.0
    except Exception:
        return None


_prev_cpu_sample = None


def get_cpu_percent():
    """시스템 전체 CPU 사용률 0~100 (전 코어 합산을 100%로 정규화).

    /proc/stat은 부팅 이후 누적 시간이라 값 하나로는 사용률을 알 수 없다.
    직전 호출과의 차분으로 구간 사용률을 낸다 → **첫 호출은 항상 None**.
    (컨테이너 안에서도 /proc/stat은 호스트 전체 값을 보여주므로 디바이스
    전체 부하가 잡힌다. 이 프로세스만의 사용률이 아니다.)
    """
    global _prev_cpu_sample
    try:
        with open('/proc/stat') as f:
            parts = f.readline().split()
        if not parts or parts[0] != 'cpu':
            return None
        vals = [int(v) for v in parts[1:]]
    except Exception:
        return None
    if len(vals) < 4:
        return None
    idle = vals[3] + (vals[4] if len(vals) > 4 else 0)   # idle + iowait
    total = sum(vals)
    prev, _prev_cpu_sample = _prev_cpu_sample, (total, idle)
    if prev is None:
        return None
    d_total, d_idle = total - prev[0], idle - prev[1]
    if d_total <= 0:
        return None
    return max(0.0, min(100.0, (d_total - d_idle) / d_total * 100.0))


class FrameGrabber:
    """카메라를 별도 스레드에서 계속 읽어 항상 최신 프레임 1장만 보관.

    함정 방지: 추론 루프가 카메라 캡처 속도보다 느리면(예: 33ms/frame 캡처 vs
    90ms/frame 추론) `cap.read()`를 메인 루프에서 직접 부를 경우 드라이버
    버퍼에 안 읽힌 프레임이 쌓여 지연이 계속 누적된다 -
    `cv2.CAP_PROP_BUFFERSIZE`는 V4L2/UVC 드라이버에 따라 무시되는 경우가
    흔해 안전장치가 못 됨. 큐 대신 "최신 프레임 1장 덮어쓰기" 방식으로
    이 누적을 원천 차단한다.
    """

    def __init__(self, cap):
        self._cap = cap
        self._lock = threading.Lock()
        self._frame = None
        self._frame_id = 0
        self._dropped = 0
        self._stop = threading.Event()
        self._thread = threading.Thread(target=self._run, daemon=True)

    def start(self):
        self._thread.start()
        return self

    def _run(self):
        while not self._stop.is_set():
            ret, frame = self._cap.read()
            if not ret or frame is None:
                self._dropped += 1
                time.sleep(0.01)
                continue
            with self._lock:
                self._frame = frame
                self._frame_id += 1

    def latest(self):
        """(frame_id, frame) - frame_id로 새 프레임 여부 판단."""
        with self._lock:
            return self._frame_id, self._frame

    @property
    def dropped(self):
        return self._dropped

    def stop(self):
        self._stop.set()
        self._thread.join(timeout=1.0)


def parse_args():
    ap = argparse.ArgumentParser(description="UNO Q Health Care Bot")
    ap.add_argument("model", help="MoveNet Thunder INT8 TFLite 경로")
    ap.add_argument("--mode", choices=["squat", "overhead", "lateral", "guard"], default="squat",
                    help="운동 종목 (웹 UI에서 /api/mode로 실시간 변경). 정면 선택식 - 자동분류 없음. "
                         "guard = 경비 모드(운동과 무관, 전환 5초 뒤부터 사람 감지 시 촬영+로그)")
    ap.add_argument("--camera", type=int, default=0)
    ap.add_argument("--width", type=int, default=640)
    ap.add_argument("--height", type=int, default=480)
    ap.add_argument("--threads", type=int, default=4)
    ap.add_argument("--conf", type=float, default=0.3,
                    help="keypoint confidence 임계")
    ap.add_argument("--side", choices=["left", "right", "avg", "better"], default="better",
                    help="카운터 입력 각도 좌/우 선택 (기본 better)")
    ap.add_argument("--max-frames", type=int, default=0)
    ap.add_argument("--print-every", type=int, default=15)

    # 임계 (종목별 default가 다르므로 종목마다 별도 플래그로 노출)
    ap.add_argument("--squat-down-th", type=float, default=100.0)
    ap.add_argument("--squat-up-th", type=float, default=140.0)
    ap.add_argument("--overhead-down-th", type=float, default=60.0)
    ap.add_argument("--overhead-up-th", type=float, default=140.0)
    ap.add_argument("--lateral-down-th", type=float, default=35.0)
    ap.add_argument("--lateral-up-th", type=float, default=80.0)
    ap.add_argument("--min-dwell-ms", type=float, default=200.0)

    # PTZ (ST3215 시리얼 버스 서보 직결 - MCU 경유 아님)
    ap.add_argument("--serial", default="",
                    help="서보 버스 어댑터 포트 (예: /dev/ttyUSB0, COM9). 미지정 시 PTZ 비활성")
    ap.add_argument("--baudrate", type=int, default=1_000_000, help="ST3215 버스 기본 baud")
    ap.add_argument("--frame-out-grace", type=int, default=15, help="미검출 N프레임 후 LOST")
    ap.add_argument("--ptz-cooldown-ms", type=float, default=250.0)
    ap.add_argument("--sector-side", type=float, default=1.0 / 6.0,
                    help="좌우 섹터 폭 (기본 1/6 → 무릎을 중앙 4/6 밴드에 유지)")
    ap.add_argument("--pitch-deadzone", type=float, default=0.20,
                    help="pitch 데드존 - 넓게 잡아 스쿼트 상하 동작을 무시")
    ap.add_argument("--pitch-target-y", type=float, default=0.62,
                    help="pitch 세로 기준점 (무릎이 화면 하단 1/3쯤 오도록)")
    ap.add_argument("--lock-frames", type=int, default=10,
                    help="존 안에 N프레임 머물면 잠금(정지). 0=잠금 끄기")
    ap.add_argument("--track-scale", type=float, default=0.5, help="추적 속도 배율")
    ap.add_argument("--both-knee-scale", type=float, default=0.5,
                    help="양 무릎 보일 때 추가 속도 배율")
    ap.add_argument("--yaw-sign", type=int, default=1, choices=[-1, 1])
    ap.add_argument("--pitch-sign", type=int, default=-1, choices=[-1, 1],
                    help="2026-08-07 재조립 이후 -1이 기본(실측 확인됨). 재조립 전 방향이면 1")

    # HTTP
    ap.add_argument("--serve", type=int, default=0,
                    help="HTTP MJPEG 포트 (0 = 비활성)")
    ap.add_argument("--jpeg-quality", type=int, default=70)
    ap.add_argument("--idle-skip-draw", action="store_true",
                    help="스트림 뷰어가 0명이면 그리기+인코딩을 건너뛴다(연산 집중 모드). "
                         "미지정 시 기존과 동일하게 항상 그린다.")
    return ap.parse_args()


def select_counter(mode: str, squat_c, overhead_c, lateral_c):
    """모드(웹 UI에서 선택)로 카운터를 고른다. 전부 정면 종목이라 자동분류 없음.
    guard는 운동이 아니므로 카운터 없음 (사람 감지 촬영만 동작)."""
    if mode == "overhead":
        return overhead_c, "overhead"
    if mode == "lateral":
        return lateral_c, "lateral"
    if mode == "guard":
        return None, "guard"
    return squat_c, "squat"


def compute_angle(kp, exercise: str, conf_th: float, side: str):
    """선택된 운동에 따라 좌/우 각도 + 대표 각도 반환."""
    if exercise == "squat":
        left = knee_angle(kp, "left", conf_th)
        right = knee_angle(kp, "right", conf_th)
    elif exercise in ("overhead", "lateral"):
        left = shoulder_elev_angle(kp, "left", conf_th)
        right = shoulder_elev_angle(kp, "right", conf_th)
    else:
        return None, None, None
    return left, right, pick_angle(left, right, mode=side)


def main():
    args = parse_args()

    model_path = Path(args.model)
    if not model_path.exists():
        sys.exit(f"ERROR: model not found: {model_path}")

    itp = tflite.Interpreter(model_path=str(model_path), num_threads=args.threads)
    itp.allocate_tensors()
    in_d = itp.get_input_details()[0]
    out_d = itp.get_output_details()[0]
    _, h_in, w_in, _ = (int(x) for x in in_d['shape'])
    assert h_in == w_in, f"expected square input, got {h_in}x{w_in}"

    print(f"== UNO Q Health Care Bot ({RUNTIME}) ==")
    print(f"  model    : {model_path}")
    print(f"  input    : {w_in}x{h_in} {in_d['dtype'].__name__}")
    print(f"  mode     : {args.mode}")
    print(f"  camera   : /dev/video{args.camera} {args.width}x{args.height}")
    print(f"  threads  : {args.threads}, conf {args.conf}, side {args.side}")
    print(f"  squat    : down<{args.squat_down_th}, up>{args.squat_up_th}")
    print(f"  overhead : down<{args.overhead_down_th}, up>{args.overhead_up_th}")
    print(f"  lateral  : down<{args.lateral_down_th}, up>{args.lateral_up_th}")
    print(f"  ptz      : serial={args.serial or '(disabled)'} sector={args.sector_side:.3f} "
          f"lock={args.lock_frames}f grace={args.frame_out_grace}f scale={args.track_scale}")
    if args.serve:
        print(f"  serve    : http://<device-ip>:{args.serve}/ (DEBUG no-auth)")
    print()

    # PTZ
    ptz = PTZController(
        serial_port=args.serial or None,
        baudrate=args.baudrate,
        conf_th=args.conf,
        frame_out_grace=args.frame_out_grace,
        command_cooldown_ms=args.ptz_cooldown_ms,
        sector_side=args.sector_side,
        pitch_deadzone=args.pitch_deadzone,
        pitch_target_y=args.pitch_target_y,
        lock_frames=args.lock_frames,
        track_scale=args.track_scale,
        both_knee_scale=args.both_knee_scale,
        yaw_sign=args.yaw_sign,
        pitch_sign=args.pitch_sign,
    )
    ptz.open()

    # Counters - 세 종목 모두 생성 (웹에서 모드 전환 시 각 상태 유지)
    squat_c = SquatCounter(args.squat_down_th, args.squat_up_th, args.min_dwell_ms)
    overhead_c = OverheadPressCounter(args.overhead_down_th, args.overhead_up_th, args.min_dwell_ms)
    lateral_c = LateralRaiseCounter(args.lateral_down_th, args.lateral_up_th, args.min_dwell_ms)

    _last_fps = {"value": 0.0}
    app_state.set_mode(args.mode)

    # HTTP
    if args.serve:
        init_app(ptz=ptz, squat_c=squat_c, overhead_c=overhead_c, lateral_c=lateral_c,
                 avg_fps_fn=lambda: _last_fps["value"])
        try:
            start_server(args.serve)
            print(f"  [http] started on port {args.serve}\n")
            print(f"  [app]  http://<device-ip>:{args.serve}/app  (viewer)")
            print(f"  [app]  http://<device-ip>:{args.serve}/app?role=operator  (operator)\n")
        except Exception as e:
            sys.exit(f"ERROR: failed to start HTTP server: {e}")

    # Camera
    cap = cv2.VideoCapture(args.camera)
    if not cap.isOpened():
        sys.exit(f"ERROR: cannot open camera /dev/video{args.camera}")
    cap.set(cv2.CAP_PROP_FRAME_WIDTH, args.width)
    cap.set(cv2.CAP_PROP_FRAME_HEIGHT, args.height)
    cap.set(cv2.CAP_PROP_BUFFERSIZE, 1)
    actual_w = int(cap.get(cv2.CAP_PROP_FRAME_WIDTH))
    actual_h = int(cap.get(cv2.CAP_PROP_FRAME_HEIGHT))
    print(f"  actual   : {actual_w}x{actual_h}\n")

    grabber = FrameGrabber(cap).start()

    loop_window = deque(maxlen=30)
    frame_idx = 0
    last_frame_id = -1
    last_orient = None
    t_start = time.perf_counter()

    print("[run] start (Ctrl+C to stop)\n")

    try:
        while True:
            frame_id, frame = grabber.latest()
            if frame is None or frame_id == last_frame_id:
                # 아직 새 프레임 없음 - 그리버 스레드가 캡처하는 동안 바쁜 대기 회피
                time.sleep(0.005)
                continue
            last_frame_id = frame_id
            t0 = time.perf_counter()

            padded, pad_info = letterbox_square(frame, target=h_in)
            rgb = cv2.cvtColor(padded, cv2.COLOR_BGR2RGB)
            x = np.expand_dims(rgb.astype(np.uint8), 0)

            itp.set_tensor(in_d['index'], x)
            itp.invoke()
            raw = itp.get_tensor(out_d['index'])  # [1,1,17,3]

            kp = unletterbox_kp(raw[0, 0], pad_info, target=h_in)

            # 운동 종목 결정 (mode는 /api/mode로 앱에서 실시간 변경 가능) - PTZ 추적점
            # 선택보다 먼저 필요 (스쿼트면 무릎 가중 추적으로 바꿔야 하므로)
            orient = body_orientation(kp, args.conf)
            if orient is not None:
                last_orient = orient
            live_mode = app_state.get_mode() if args.serve else args.mode
            counter, exercise = select_counter(live_mode, squat_c, overhead_c, lateral_c)

            # 통계/오버레이용 사람 중심점 (PTZ 추적점과는 별개)
            if exercise == "squat":
                x_norm, y_norm = person_center_weighted(kp, actual_h, actual_w, args.conf)
            else:
                x_norm, y_norm = person_center_normalized(kp, actual_h, actual_w, args.conf)

            # PTZ 추적 - 종목별 타깃/프레이밍: 스쿼트=하체(무릎), 상체운동=상체(어깨,
            # 머리 위 팔이 안 잘리게). 컨트롤러가 keypoint에서 목표점을 직접 산출.
            ptz.set_track_mode(exercise)
            now_ms = time.perf_counter() * 1000.0
            ptz_cmd = ptz.update(kp, actual_h, actual_w, now_ms)

            left = right = chosen = None
            rep_event = None
            if counter is not None:
                left, right, chosen = compute_angle(kp, exercise, args.conf, args.side)
                rep_event = counter.update(chosen, now_ms=now_ms)

            # === 경비 모드: (무장+사람감지) 자동 트리거는 쿨다운(guard_try_capture)을
            # 적용하지만, "직접 촬영" 버튼은 무조건 즉시 찍는다 - 쿨다운을 공유시키면
            # 사람이 화면 안에 계속 있어(테스트 중 본인처럼) 자동 촬영이 쿨다운을
            # 계속 선점해서 버튼을 눌러도 조용히 씹히는 문제가 있었다. force_capture
            # 플래그는 guard 모드가 아닐 때도 매 프레임 소비해줘야 버튼을 눌러둔 채
            # 모드를 벗어나도 다음에 guard로 돌아왔을 때 오래된 요청이 갑자기
            # 튀어나오지 않는다.
            manual_capture = app_state.guard_pop_force_capture()
            guard_event = None
            if exercise == "guard":
                auto_ok = (app_state.guard_is_armed() and guard_capture.person_detected(kp, args.conf)
                           and app_state.guard_try_capture())
                if auto_ok:
                    guard_event = guard_capture.save_capture(frame, time.time() * 1000.0)
                    print(f"  [guard] capture {guard_event['file']}  ({guard_event['time']})")
                elif manual_capture:
                    app_state.guard_register_manual_capture()
                    guard_event = guard_capture.save_capture(frame, time.time() * 1000.0, meta={"manual": True})
                    print(f"  [guard] capture {guard_event['file']}  ({guard_event['time']})  (manual)")

            # === Draw overlay: 스켈레톤(pose)만 ===
            # 수치 텍스트(FPS/각도/REPS/PTZ)는 웹 UI가 stats.json으로 표시하므로
            # 영상에 굽지 않는다 — 중복 제거 + putText 비용 절감. 골격은 유지.
            #
            # --idle-skip-draw(연산 집중 모드): 스트림 뷰어가 0명이면 그리기+
            # 인코딩을 통째로 건너뛴다. 플래그가 없으면(기본) 항상 그려서
            # 기존 동작과 100% 동일하다. stats.json 숫자는 어느 경우든 계속 흐른다.
            want_video = True
            if args.serve and args.idle_skip_draw:
                want_video = viewer_count() > 0
            if want_video:
                annotated = frame.copy()
                # guard(경비)는 운동이 아니라 포즈 스켈레톤을 굳이 보여줄 필요가
                # 없다 - 원본 카메라 화면만 내보낸다.
                if exercise != "guard":
                    highlight = _HIGHLIGHT_ARM if exercise in ("overhead", "lateral") else _HIGHLIGHT_SQUAT
                    draw_pose(annotated, kp, conf_th=args.conf, highlight=highlight)
            else:
                annotated = None

            # FPS 계산 (영상 오버레이는 없앴지만 stats.json/로그에 여전히 필요)
            ms_loop = (time.perf_counter() - t0) * 1000.0
            loop_window.append(ms_loop)
            avg_ms = sum(loop_window) / len(loop_window)
            fps = 1000.0 / avg_ms if avg_ms > 0 else 0.0
            _last_fps["value"] = round(fps, 2)

            # PTZ 스냅샷 (stats.json + 아래 print/로그에서 사용)
            ptz_snap = ptz.snapshot()

            frame_idx += 1

            # HTTP 스트림 갱신
            if args.serve:
                live = {
                    "frame": frame_idx,
                    "fps": round(fps, 2),
                    "loop_ms": round(ms_loop, 2),
                    "mode": live_mode,
                    "exercise_active": exercise,
                    "orientation": last_orient,
                    "angle_deg": {
                        "left": round(left, 1) if left is not None else None,
                        "right": round(right, 1) if right is not None else None,
                        "used": round(chosen, 1) if chosen is not None else None,
                    },
                    "person_center_norm": [
                        round(x_norm, 3) if x_norm is not None else None,
                        round(y_norm, 3) if y_norm is not None else None,
                    ],
                    "squat": squat_c.snapshot(),
                    "overhead": overhead_c.snapshot(),
                    "lateral": lateral_c.snapshot(),
                    "ptz": ptz_snap,
                    "last_ptz_cmd": ptz_cmd,
                    "dropped_frames": grabber.dropped,
                    "rss_mb": round(get_rss_mb() or 0.0, 1),
                    "cpu_temp_c": round(cpu_temp_c, 1) if (cpu_temp_c := get_cpu_temp_c()) is not None else None,
                    "cpu_percent": round(cpu_pct, 1) if (cpu_pct := get_cpu_percent()) is not None else None,
                }
                if rep_event:
                    live["last_event"] = {
                        "exercise": exercise,
                        "type": rep_event[0],
                        "rep_total": rep_event[1],
                        "min_angle_deg": round(rep_event[2], 1),
                        "frame": frame_idx,
                    }
                if guard_event:
                    live["last_event"] = {
                        "exercise": "guard",
                        "type": "GUARD_CAPTURE",
                        "file": guard_event["file"],
                        "time": guard_event["time"],
                        "frame": frame_idx,
                    }
                update_live_state(annotated, live, q=args.jpeg_quality, encode=want_video)

            if rep_event:
                print(f"  ★ {exercise.upper()} REP #{rep_event[1]}  "
                      f"bottom={rep_event[2]:.0f}°  (frame {frame_idx})")

            if frame_idx % args.print_every == 0:
                la = f"{left:.0f}" if left is not None else "?"
                ra = f"{right:.0f}" if right is not None else "?"
                ex = exercise or "-"
                reps = counter.reps if counter is not None else 0
                print(f"[{frame_idx:5d}] fps={fps:5.2f}  {ex:>6s} "
                      f"L={la:>3s} R={ra:>3s}°  reps={reps:3d}  "
                      f"ptz={ptz_snap['state']:<8s} cmd={ptz_cmd or '-'}")

            if args.max_frames > 0 and frame_idx >= args.max_frames:
                break

    except KeyboardInterrupt:
        print("\n[stop] interrupted")
    finally:
        grabber.stop()
        try:
            cap.release()
        except Exception:
            pass
        ptz.close()

        elapsed = time.perf_counter() - t_start
        print()
        print("=" * 64)
        print(f"  SUMMARY  frames={frame_idx}  elapsed={elapsed:.1f}s")
        print(f"     fps_effective : {frame_idx / max(elapsed, 1e-9):.2f}")
        print(f"     dropped       : {grabber.dropped}")
        print(f"     squat reps    : {squat_c.reps}")
        print(f"     overhead reps : {overhead_c.reps}")
        print(f"     lateral reps  : {lateral_c.reps}")
        print(f"     ptz cmds      : pan={ptz.n_pan_cmds} tilt={ptz.n_tilt_cmds}")
        print("=" * 64)


if __name__ == "__main__":
    main()

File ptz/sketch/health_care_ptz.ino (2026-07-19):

/*
 * health_care_ptz.ino — UNO Q (STM32U585) PTZ yaw/pitch 제어 (ST3215 버스 서보).
 *
 * 하드웨어 (2026-07 변경, PWM 직결 → 시리얼 버스 서보):
 *
 *   [Bus Servo Adapter] --daisy--> [Yaw 서보 ID=1] --daisy--> [Pitch 서보 ID=2]
 *        (전원+제어회로 통합 어댑터, ST3215용)
 *
 *   어댑터 ↔ UNO Q MCU: TTL UART 2선 (TX/RX). Python 브릿지가 이미 USB Serial
 *   (Serial)을 점유하므로, 버스 서보는 별도 하드웨어 UART(BUS_SERVO_SERIAL,
 *   기본 Serial1)를 사용. ⚠ UNO Q 실제 보드에서 TX1/RX1 핀 번호를 실크스크린/
 *   핀맵으로 확인하고 배선할 것 — 여기서는 심볼(Serial1)만 지정.
 *
 *   서보 전원은 어댑터 쪽 전용 커넥터로 공급 (ST3215 정격 6~12.6V, GND는
 *   UNO Q와 공통 필수). MCU 로직 전원과 서보 구동 전원은 분리 추천.
 *
 * ⚠ 배선 전 필수 — ID 사전 설정:
 *   ST3215는 공장 출하 시 모든 서보의 ID가 1. 체인으로 묶기 전에 서보를
 *   하나씩 어댑터에 연결해 SCServo 설정 툴(또는 st.unLockEprom/writeByte)로
 *   yaw=1, pitch=2 로 미리 나눠 기록해야 함. 그대로 체인에 물리면 ID 충돌로
 *   버스가 응답하지 않음.
 *
 * Linux 측 src/ptz_controller.py 가 보내는 텍스트 명령 프로토콜은 기존과 동일
 * (1줄=1명령, '\n' 종결, USB Serial 그대로 사용):
 *   PAN <delta_deg>\n     # yaw(ID=1, 체인 첫 번째) 각도에 delta_deg 더함
 *   TILT <delta_deg>\n    # pitch(ID=2, yaw에서 데이지체인) 각도에 delta_deg 더함
 *   CENTER\n              # yaw/pitch 중심(90°/90°) 복귀
 *   PING\n                # 응답 "PONG" (USB 헬스체크, 버스 서보 상태와 무관)
 *
 * 응답 (디버그):
 *   OK PAN=<deg> TILT=<deg>
 *   ERR <reason>
 *   PONG
 *
 * 필요 라이브러리: Feetech "SCServo" Arduino 라이브러리 (SMS_STS 클래스,
 * ST/SM/STS 시리즈 공용). Library Manager에 없으면 zip 설치.
 * ⚠ 실제 설치된 라이브러리 버전의 API(WritePosEx/Ping 시그니처)를
 * 컴파일 전에 반드시 대조할 것.
 *
 * 회전 속도:
 *   기존 PWM 버전의 STEP_DELAY=20ms/° (손가락 끼임 방지 취지)를 서보 네이티브
 *   speed 파라미터로 환산해 유지 (BUS_SPEED, 아래 매크로). 다만 실제 체감
 *   속도는 서보 가감속(ACC) 프로파일에 따라 달라지므로 실기에서 재검증 필요.
 *
 * 동작 차이 (PWM 버전 대비):
 *   이전 slew_servo()는 목표각까지 delay()로 블로킹 이동 — 명령 처리 중
 *   새 시리얼 명령을 못 받았음. 버스 서보는 WritePosEx가 논블로킹 — 목표
 *   위치만 서보에 지시하고 즉시 loop()로 복귀, 서보 자체 펌웨어가 speed/acc
 *   프로파일로 이동. 이동 중 새 명령이 오면 목표가 갱신됨 (더 반응적).
 *
 * 캘리브레이션:
 *   YAW_CENTER_TICK / PITCH_CENTER_TICK 은 "서보 자체 기계 중앙(2048)==논리
 *   90°" 가정. 실제 짐벌 조립 각도가 다르면 벤치 테스트 후 조정.
 */

#include <SCServo.h>

SMS_STS st;

#define BUS_SERVO_SERIAL   Serial1     // ⚠ UNO Q 실제 UART1 핀(TX1/RX1) 확인 후 배선
#define BUS_SERVO_BAUD     1000000     // ST3215 공장 기본 baud (변경 이력 없으면 유지)

#define YAW_ID              1          // 체인 첫 번째 서보 (어댑터 직결)
#define PITCH_ID            2          // yaw 에서 데이지체인된 두 번째 서보

#define YAW_MIN             0          // 중앙 ±90°, 실기 좌/우 90° 실측 확인(2026-07-17)
#define YAW_MAX             180
#define YAW_CENTER          90
#define PITCH_MIN           60         // 중앙 ±30°, 실기 위/아래 30° 실측 확인(2026-07-17,
#define PITCH_MAX           120        // 케이블 여유가 처음 추정한 ±20°보다 더 있었음)
#define PITCH_CENTER        90

// 서보 물리 장착 기준 틱 — 서보 EEPROM의 Homing_Offset(addr 31~32, STS3215은
// 부호비트가 bit11, ±2047 범위 — huggingface/lerobot의 feetech 구현으로 검증됨)을
// 실측 조정해서 "지금 이 물리 자세"가 PRESENT_POSITION에서 정확히 tick 2047(≈2048,
// 0~4095 정중앙)로 읽히도록 캘리브레이션 완료(2026-07-17,
// scripts/test_st3215_serial.py set-center, torque off 상태에서 실행해 물리적으로는
// 전혀 안 움직임). 정중앙이라 ±180° 여유가 양쪽에 다 확보되어 yaw ±90° / pitch ±20°
// 전부 0/4095 경계 없이 들어감.
// ⚠ 캘리브레이션 후 torque를 다시 켤 때는 반드시 먼저 Goal_Position을 현재
// Present_Position(2048)에 맞춰 동기화한 뒤 켤 것 — 안 그러면 서보가 예전 goal
// position으로 갑자기 회전할 수 있음(실기 사고 이력 있음, docs/issues/ 참고).
// 재조립 시 서보 EEPROM 쪽을 다시 맞추면 이 상수는 2048 그대로 둬도 됨.
#define YAW_CENTER_TICK      2048      // ID=1 (yaw)
#define PITCH_CENTER_TICK    2048      // ID=2 (pitch)
#define TICKS_PER_DEG        (4095.0f / 360.0f)   // ST3215: 12bit(0~4095) = 0~360°

#define STEP_DELAY_MS_EQUIV  20        // 기존 PWM 버전 기준 속도 (20ms/°) — 손가락 끼임 방지
#define BUS_SPEED   ((uint16_t)((1000.0f / STEP_DELAY_MS_EQUIV) * TICKS_PER_DEG))  // ≈569 tick/s
#define BUS_ACC     20                 // 가감속 (0~254, 클수록 급하게 붙음) — 실기 튜닝 필요

#define SERIAL_BAUD          115200    // USB(Python 브릿지) — 기존과 동일
#define LINE_BUF_SIZE        64

int current_yaw   = YAW_CENTER;
int current_pitch = PITCH_CENTER;

char line_buf[LINE_BUF_SIZE];
uint8_t line_len = 0;

int16_t deg_to_tick(int deg, int center_deg, int center_tick) {
    long tick = center_tick + lround((deg - center_deg) * TICKS_PER_DEG);
    if (tick < 0) tick = 0;
    if (tick > 4095) tick = 4095;
    return (int16_t)tick;
}

void move_yaw(int target_deg) {
    if (target_deg < YAW_MIN) target_deg = YAW_MIN;
    if (target_deg > YAW_MAX) target_deg = YAW_MAX;
    current_yaw = target_deg;
    st.WritePosEx(YAW_ID, deg_to_tick(current_yaw, YAW_CENTER, YAW_CENTER_TICK), BUS_SPEED, BUS_ACC);
}

void move_pitch(int target_deg) {
    if (target_deg < PITCH_MIN) target_deg = PITCH_MIN;
    if (target_deg > PITCH_MAX) target_deg = PITCH_MAX;
    current_pitch = target_deg;
    st.WritePosEx(PITCH_ID, deg_to_tick(current_pitch, PITCH_CENTER, PITCH_CENTER_TICK), BUS_SPEED, BUS_ACC);
}

void send_status(const char *prefix) {
    Serial.print(prefix);
    Serial.print(" PAN=");
    Serial.print(current_yaw);
    Serial.print(" TILT=");
    Serial.println(current_pitch);
}

// "PAN +8.5" / "TILT -5" 형태 파싱
bool parse_delta(const char *args, float *out_delta) {
    if (*args == '\0') return false;
    char *endp = nullptr;
    float v = strtod(args, &endp);
    if (endp == args) return false;
    *out_delta = v;
    return true;
}

void handle_line(char *buf) {
    // 토큰 분리 — 첫 공백까지가 cmd
    char *sp = strchr(buf, ' ');
    const char *args = "";
    if (sp != nullptr) {
        *sp = '\0';
        args = sp + 1;
    }

    if (strcmp(buf, "PING") == 0) {
        Serial.println("PONG");
        return;
    }

    if (strcmp(buf, "CENTER") == 0) {
        move_yaw(YAW_CENTER);
        move_pitch(PITCH_CENTER);
        send_status("OK");
        return;
    }

    if (strcmp(buf, "PAN") == 0) {
        float delta = 0.0;
        if (!parse_delta(args, &delta)) { Serial.println("ERR pan_delta"); return; }
        move_yaw(current_yaw + (int)delta);
        send_status("OK");
        return;
    }

    if (strcmp(buf, "TILT") == 0) {
        float delta = 0.0;
        if (!parse_delta(args, &delta)) { Serial.println("ERR tilt_delta"); return; }
        move_pitch(current_pitch + (int)delta);
        send_status("OK");
        return;
    }

    Serial.print("ERR unknown_cmd ");
    Serial.println(buf);
}

void setup() {
    Serial.begin(SERIAL_BAUD);
    BUS_SERVO_SERIAL.begin(BUS_SERVO_BAUD);
    st.pSerial = &BUS_SERVO_SERIAL;

    delay(500);

    // 부팅 시 두 서보 응답 확인 — 배선/ID 설정 누락을 조기에 발견하기 위함
    bool yaw_ok   = (st.Ping(YAW_ID)   != -1);
    bool pitch_ok = (st.Ping(PITCH_ID) != -1);
    if (!yaw_ok)   Serial.println("ERR yaw_servo_not_found (ID=1)");
    if (!pitch_ok) Serial.println("ERR pitch_servo_not_found (ID=2)");

    move_yaw(YAW_CENTER);
    move_pitch(PITCH_CENTER);
    delay(500);
    Serial.println("READY health_care_ptz (bus)");
    send_status("OK");
}
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

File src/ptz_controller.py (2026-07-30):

"""PTZ 추적 컨트롤러 - ST3215 시리얼 버스 서보 직접 구동 (MCU 경유 아님).

추적 로직 (scripts/ptz_camera_track.py v2에서 실기 검증된 것을 이식):
  - 목표점: 두 무릎 중점(양쪽 다 보일 때) → 엉덩이 중심 → 몸통 중심 폴백.
    한쪽 무릎만 보일 때 그 다리로 카메라가 쏠리는 것을 방지.
  - EMA 스무딩으로 키포인트 지터 완화.
  - yaw: 화면을 좌 1/6 · 중앙 4/6 · 우 1/6 로 나눠, 목표(+양 무릎)가 중앙 4/6
    밴드 안이면 정지. 밖으로 나가야 팬.
  - pitch: 데드존 기반 (목표 y 기준점은 pitch_target_y, 기본 화면 중앙 0.5).
  - 획득→잠금: 존 안에 lock_frames 연속 머물면 LOCK(명령 정지), 재개는
    히스테리시스로 충분히 벗어날 때만 → 미세 흔들림(도리도리) 제거.
  - 속도: track_scale(기본 1/2), 양 무릎 다 보이면 both_knee_scale 추가(총 1/4).

안전:
  - 모든 서보 명령은 소프트리밋으로 클램프 (yaw 중앙±90, pitch 중앙±30 - 실측값).
  - 안전속도(≈569 tick/s = 20ms/° 등가) 고정 - 손가락 끼임 방지.
  - torque는 항상 "현재 위치로 goal 동기화 → ON" 순서로 켬 (켜지는 순간 점프 방지).
  - 시작 시 중앙으로 정렬 후 추적 시작.

시리얼 미지정/열기 실패/서보 무응답이면 disabled 모드 - 추적 상태 계산만 하고
서보 명령은 안 보냄 (웹 UI는 그대로 동작).
"""
import time
from dataclasses import dataclass, field
from enum import Enum
from typing import Optional

from pose_utils import (
    KP, knee_center_normalized, hip_center_normalized, person_center_normalized,
    shoulder_center_normalized,
)

try:
    import st3215_bus as bus
except Exception:  # pyserial 부재 등
    bus = None


class TrackState(Enum):
    IN_FRAME = "in_frame"      # 목표가 존 안 (또는 잠금) - 명령 없음
    EDGE = "edge"              # 존 밖 - 추적 중
    LOST = "lost"              # 미검출 grace 통과


@dataclass
class PTZController:
    # 연결
    serial_port: Optional[str] = None
    baudrate: int = 1_000_000            # ST3215 버스 기본 baud
    yaw_id: int = 1
    pitch_id: int = 2

    # 각도 컨벤션 (tick 2047 캘리브레이션 = 180°), 실측 가동범위
    yaw_center: float = 180.0
    yaw_min: float = 90.0
    yaw_max: float = 270.0
    pitch_center: float = 180.0
    pitch_min: float = 150.0
    pitch_max: float = 210.0

    # 추적 파라미터
    conf_th: float = 0.3
    sector_side: float = 1.0 / 6.0       # 좌우 섹터 각 1/6 → 중앙 4/6 밴드
    # pitch는 무릎 높이를 쫓지 않는다: 스쿼트 중 무릎이 상하로 크게 움직이므로
    # 좁은 데드존이면 카메라가 매 rep마다 끄덕인다. 기준점을 하단쪽(0.62)에 두고
    # 데드존을 넓게 잡아 "큰 프레이밍 오차"만 교정한다.
    pitch_deadzone: float = 0.20
    pitch_target_y: float = 0.62         # pitch 세로 기준점 (무릎이 화면 하단 1/3쯤)
    # 상체 모드(숄더프레스/레터럴): 무릎 대신 어깨를 추적하고, 어깨를 화면
    # 하단쪽(pitch_target_y_upper)에 둬 머리 위로 든 팔이 프레임 밖으로 잘리지
    # 않게 한다. 어깨는 상하로 거의 안 흔들리므로 데드존은 좁게. main.py가
    # set_track_mode()로 운동 종목에 맞춰 넘긴다.
    pitch_target_y_upper: float = 0.64
    pitch_deadzone_upper: float = 0.15
    track_mode: str = "lower"            # "lower"(스쿼트: 무릎) | "upper"(상체: 어깨)
    reengage: float = 0.18
    yaw_reengage_hyst: float = 0.05
    lock_frames: int = 10
    smooth_alpha: float = 0.4
    # 추적 속도는 deg/s로 직접 표현한다 (프레임 수와 무관).
    # 원래는 "프레임당 도수"(gain=8.0, max_step=4.0 deg/frame)였는데, 이 값이
    # 개발 PC(~29 FPS) 기준이라 11 FPS인 UNO Q에서는 각속도가 1/2.6로 떨어져
    # 서보가 22ms 움직이고 228ms 멈추는 "톡톡" 끊김이 생겼다. 아래 값은 기존
    # 튜닝에 29를 곱해 환산한 것이라 PC 동작은 그대로 유지된다.
    gain_deg_per_s: float = 232.0        # 정규화 오차 1.0당 각속도 (8.0 x 29)
    max_deg_per_s: float = 116.0         # 오차가 커도 이 이상은 안 돈다 (4.0 x 29)
    track_scale: float = 0.5             # 추적 속도 1/2
    both_knee_scale: float = 0.5         # 양 무릎 보이면 추가 1/2 (총 1/4)
    # -> 양 무릎이 보일 때 실제 상한은 116 x 0.5 x 0.5 = 29 deg/s
    max_dt_s: float = 0.15               # dt 상한 - LOST 복귀 직후 튀는 것 방지
    yaw_sign: int = 1
    pitch_sign: int = 1
    frame_out_grace: int = 15            # 미검출 N프레임 후 LOST
    # 추적 손실 복구 사다리 (yaw 전용, pitch는 그대로 둔다)
    #   관성 -> 그 자리 대기 -> 관성 이전으로 복귀 후 대기 -> 중앙 복귀 후 정지
    # 어느 단계든 재검출되면 즉시 취소하고 정상 추적으로 돌아간다.
    # 관성 방향/속도는 "마지막 yaw 각속도"를 쓴다. 사람이 중앙에 가만히 있어
    # 카메라가 안 움직이던 중이면 속도가 0이라 관성이 아예 안 걸린다 —
    # 검출만 깜빡인 경우의 헛발질이 이 규칙으로 자연히 걸러진다.
    coast_start_misses: int = 3          # 단발 깜빡임 무시 - 연속 N프레임부터 관성
    # 관성 지속 "프레임 수" — 시간이 아니라 프레임이므로 FPS가 다르면 지속 시간과
    # 이동 거리가 달라진다 (11 FPS에서 15프레임 = 1.36초, 29 FPS면 0.52초).
    # 알려진 한계로 남겨둔 부분. 상세: docs/history/2026-07-19_02
    coast_frames: int = 15               # 11 FPS 기준 약 1.36초
    # 프레임당 속도 감쇠. 1.0이면 감쇠 없이 등속으로 끝까지 돌다 딱 멈춘다.
    # 관성 이동 "거리"를 결정하는 지배적 인자 (coast_frames는 거의 영향 없음):
    #   0.8 -> 27도, 0.9 -> 44도, 1.0 -> 84도  (15프레임, 11 FPS 기준)
    coast_decay: float = 0.9
    coast_hold_s: float = 1.0            # 관성 끝 지점에서 대기
    return_hold_s: float = 2.0           # 관성 이전 위치에서 대기
    # 화면 내 이동량(정규화 0~1)을 각도로 환산하는 계수 = 카메라 수평 화각.
    # 정확한 값을 모르면 대략 60도로 두고 실측으로 보정한다 (카메라를 알려진
    # 각도만큼 돌려놓고 피사체가 화면에서 몇 % 밀리는지 재면 나온다).
    coast_fov_deg: float = 60.0
    # 서보(50 deg/s)가 목표각이 미는 속도(최대 29 deg/s)보다 1.7배 빠르다.
    # 250ms 주기로 던지면 서보가 먼저 도착해 주기의 40~70%를 멈춰 있어서
    # "톡톡" 끊겨 보인다. 프레임 간격(11 FPS = 91ms)보다 짧게 줘서 사실상
    # 매 프레임 갱신되게 한다. 1Mbaud에 명령 15바이트라 버스 부하는 무시 가능.
    command_cooldown_ms: float = 80.0
    servo_speed: int = 569               # 안전속도
    servo_acc: int = 20
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

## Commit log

2026-07-19 v3: PTZ 시간 기준 제어 + 추적 손실 관성 복구
    UNO Q 실기 배포 시점의 전체 스냅샷.
    PTZ 제어
    - 추적 속도를 프레임당 -> 초당(deg/s)으로 전환. 프레임레이트와 무관해져
    PC(29 FPS)와 UNO Q(11 FPS)에서 같은 각속도가 나온다. 기존에는 11 FPS에서
    각속도가 64% 부족해 톡톡 끊겼다.
    - 명령 쿨다운 250ms -> 80ms. 서보(50 deg/s)가 목표각이 밀리는 속도(29 deg/s)
    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
    [finalp.3mf]
2026-07-19 docs: 디바이스 노드 이름 불안정성 정정 + 재조립 체크리스트
    노드 번호를 규칙으로 적어둔 것이 틀렸음이 실측으로 드러나 정정한다.
    USB 연결 위치/순서와 부팅 시 드라이버 등록 순서에 따라 매번 바뀐다.
    - HANDOFF 2절에 "실행 전에 미리 알아둬야 하는 것" 신설. 카메라/시리얼 노드를
    실행 직전 매번 확인하도록. "video2 이상" 규칙은 폐기 — 07-19 실측은 정반대로
    USB 카메라가 video0·1, Venus 코덱이 video2·3이었다
    - HANDOFF 5-2절 정정 — 배포는 완료됐고 실측이 남았음을 반영
    - issues/2026-07-19_01 신규 — 노드 이름 불안정성의 원인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
2026-07-19 v3: 추적 손실 관성 추적 기능 추가
    실기에서 "빠르게 프레임을 벗어나면 관성이 걸리지 않는다"는 피드백을 받아
    관성의 근거 자체를 바꿨다.
    원인 — 데드존 밴드
    관성 속도를 카메라의 마지막 각속도에서 가져왔는데, 이 값은 중앙 4/6 밴드
    밖일 때만 갱신된다. 빠르게 나가면 그 밴드를 한 프레임도 밟지 않고 사라져
    각속도가 0으로 남는다. 11 FPS면 2~3프레임 만에 중앙에서 화면 밖까지 간다.
    사용자가 후보로 지목한 3프레임 필터나 중앙 판정이 아니었다.
    수정 — 사람의 실제 각속도를 쓴다
    관성 속도 = 카메라 각속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
    [ptz_controller.py]
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2026-07-19 feat(web): 라이브 화면에 CPU 사용률 표시
    메인 화면 텔레메트리에 CPU 사용률 카드를 추가한다. 100% 기준 채움 막대를
    같이 둬서 숫자를 안 읽어도 여유가 얼마나 남았는지 보이게 했다.
    백엔드
    - get_cpu_percent() 추가. psutil 없이 /proc/stat을 직접 읽는 기존
    get_rss_mb / get_cpu_temp_c 와 같은 패턴.
    - /proc/stat은 부팅 이후 누적값이라 값 하나로는 사용률을 알 수 없다.
    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
2026-07-19 docs: 관성 추적 실기 확인 완료 반영
    화면 밖 관성 추적을 로봇에서 실제로 확인한 결과 잘 동작한다. 최초 문제였던
    "빠르게 나가면 못 따라온다"도 해소된 것을 확인했다.
    문서 세 곳이 여전히 "실기 체감 확인은 아직 안 됐다"로 남아 있어, 다음 세션이
    이미 확인된 것을 다시 검증하려 할 수 있으므로 갱신한다.
    - history/2026-07-19_02 — "실기 확인 완료" 절 추가
    - HANDOFF 4절 — 관성 항목의 미검증 표기를 확인 완료로 교체
    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
2026-07-30 feat: add LiveSession component with real-time exercise tracking and controls
    - Implemented LiveSession component for managing live exercise sessions.
    - Integrated camera feed and exercise tracking for pushups and squats.
    - Added user feedback and cues based on exercise performance.
    - Included operator controls for session management (start, pause, resume, finish).
    - Created a responsive layout with CSS for the LiveSession interface.
    - Added telemetry details for monitoring performance metrics.
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2026-08-08 feat: Add guard mode with person detection and frame capture
    - Introduced a new guard mode that operates independently from exercise modes.
    - Implemented person detection using keypoints to trigger frame captures and log entries.
    - Added functionality to save captured frames as JPEG files and maintain a log in JSONL format.
    - Updated the PTZ controller to support the new guard mode and ensure proper tracking.
    - Fixed various bugs related to mode transitions and improved mobile UI for guard mode operations.
    [angles.py, app_state.py, exercise_counter.py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]
2026-08-21 Add validation schema for v8.43 including cup profile, uno_q, lid posts, and interference details
    [column.stl, cup.stl, cup_components.3mf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]
2026-08-21 docs: 업데이트된 서보 구동 방식 및 MCU 사용 중단에 대한 설명 수정
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2026-09-08 docs: 상설 문서를 실기 런타임 기준으로 동기화
    - PTZ 명령 쿨다운을 실동작값 250ms 기준으로 정정 (CLI 기본값이 이김)
    - pitch_sign -1로 정정, IP .45 -> .50, RSS 215 -> 101MB 재측정 반영
    - 경비 모드 서술을 00/01/03/04/05/07/08에 추가
    - 웹 UI를 Fluid로 확정 명시, React 계층은 보관으로 격하
    - Tailscale Funnel 절차와 보안 예외 추가
    - design_demos 작업본이 배포본과 다름을 경고로 교체
    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
2026-09-08 chore: 벤더 서보 CAD(ST3215.step) 제거
    제조사가 자사 제품용으로 배포하는 도면이라 리포에 재배포할 성질이 아니다.
    참조하는 코드·문서도 없었다(하우징 STL은 gen_stl_v8_43_complete.py가 직접
    생성). 필요할 때 제조사 페이지에서 받아 로컬에서만 쓰도록 06에 안내를 남기고
    .gitignore로 재커밋을 막는다.
2026-09-08 chore: 공개 리포 노출 민감정보 마스킹
    Tailscale Funnel 주소/Tailscale IP, adb serial, 공유기 SSID를 실제 값 대신
    "기기에서 확인하는 방법"으로 교체했다. 이 리포는 공개라 Funnel을 켜는 순간
    주소를 아는 누구나 접속을 시도할 수 있고, 조회·스트림은 무인증이다.
    history/ 3개 파일도 예외적으로 손댔다. "history는 고치지 않는다"는 관례보다
    보안을 우선한 판단이며, 각 파일 상단에 마스킹 고지를 남겨 기록의 투명성을
    유지했다. 내용 자체는 바꾸지 않았다.
    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
2026-09-08 docs: 자매 리포(unoq-edge-ai-lines) 링크 추가
    MoveNet Thunder INT8 자산의 출처인 PoC 리포를 README 진입부와 문서 지도,
    00 §1 라인 표에 링크로 연결했다. 해당 리포는 이름이 unoq-companion-robot에서
    unoq-edge-ai-lines로 바뀌었다(4개 라인 실체에 맞춤). 로컬 폴더명은 아직
    옛 이름이라 copy_model.sh 등 경로는 그대로 유효하다.
2026-09-09 fix: 클론한 리포에서 /app이 뜨지 않던 문제 + 문서-실제 불일치 정리
    배포 웹 UI가 gitignore된 web/dist/에만 있어서, clone하면 /app이
    503 web_not_built로 떨어졌다. 문서(README §4, docs/00, docs/05 §9)는
    web/dist/index.html을 "확정 UI, 유일한 최신본"이라고 못박고 있었지만
    그 파일은 커밋 이력에 한 번도 없었다.
    배포본(자체포함 정적 HTML 1장, 49,022 B)을 커밋되는 web/app/으로 옮기고
    http_server가 web/app -> web/dist 순으로 찾도록 했다.
    - clone 직후 빌드 없이 /app이 뜬다
    - npm run build가 배포 UI를 못 덮는다 (README §8 함정이 코드에서 소멸)
    - web/app이 없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
    [angles.py, app_state.py, exercise_counter.py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]
2026-09-09 fix: PIN을 바꾸면 웹 UI 조작이 먹통되던 문제 (앞 커밋의 반쪽 수정 보완)
    앞 커밋에서 운영자 PIN을 HCB_OPERATOR_PIN으로 덮을 수 있게 했지만 서버
    쪽만 고친 반쪽이었다. 배포 UI가 ensureControl()에서 pin:"1234"를
    하드코딩하고 PIN 입력 화면이 아예 없어(docs/05 §4 "누구나 조종"),
    환경변수로 PIN을 실제로 바꾸면 claim이 invalid_pin으로 거절돼
    PTZ·모드전환·촬영 버튼이 전부 조용히 먹통이 된다. README에 "시연 전
    교체 권장"이라고 써 놓고 그대로 따르면 데모가 깨지는 상태였다.
    ensureControl()이 invalid_pin을 받았을 때만 prompt()로 한 번 묻고
    loca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
2026-09-09 docs: 제3자 자산 표기 정비 — 서체 OFL 라이선스 동봉 + THIRD_PARTY.md 신설
    공개 리포인데 남의 저작물을 재배포하면서 요구 표기가 하나도 없었다.
    서체 (가장 시급했던 것):
    - Pretendard 47개 + Gabarito 1개(백업 포함 142개)를 커밋해두고 라이선스
    사본도, 저작자 표기도 없었다. 둘 다 SIL OFL 1.1이고, OFL은 폰트를
    재배포할 때 라이선스 사본을 함께 배포할 것을 요구한다.
    - 원본 라이선스 파일을 각 프로젝트에서 그대로 받아
    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
2026-09-09 docs: README에 실물 사진 + 스쿼트 카운팅 GIF 추가
    리포에 이미지가 한 장도 없어서 "PTZ 자동 추적 · 실기 검증됨" 같은 주장에
    시각적 근거가 전혀 없었다. 시연 영상과 사진을 받아 두 장을 넣었다.
    docs/assets/robot.jpg (87 KB)
    짐벌 하우징 v8.43 실물. 헤드의 카메라, 피치 관절, 육각 베이스가 한 컷에
    들어온다. EXIF Orientation=6이라 회전을 이미지에 반영하고, 기기 모델·펌웨어
    빌드 문자열이 들어 있던 EXIF는 통째로 제거했다(공개 리포라). GPS는 없었다.
    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
2026-09-09 docs: 시연 GIF를 4개로 분리 — 종목 3종 + PTZ 추적
    앞 커밋은 스쿼트 하나뿐이라 README §1이 주장하는 기능 중 절반만 보였다.
    특히 "PTZ 자동 추적 · 실기 검증됨"은 이 프로젝트에서 가장 특징적인 항목인데
    시각적 근거가 아예 없었다. 82초 녹화를 네 구간으로 잘랐다.
    squat-counting.gif 8.8-18.6s 카운터 0->3
    overhead-press.gif 28.0-36.0s 1->3
    lateral-raise.gif 50.0-58.0s 0->2
    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
2026-09-09 docs: GIF 재인코딩 — 같은 용량에 색 48 -> 128 (ffmpeg 팔레트)
    PIL의 프레임별 중앙값 양자화는 클립 전체를 못 보고 매 프레임 따로 팔레트를
    만들어서, 벽 그라데이션에 색 뭉침이 생기고 스켈레톤 주변에 초록 잔상이
    남았다. ffmpeg의 palettegen/paletteuse로 바꿨다.
    fps=7.5,scale=320:320:flags=lanczos
    palettegen=max_colors=128:stats_mode=diff
    paletteuse=dither=none:diff_mode=rectangle
    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
2026-09-09 docs: GIF 해상도 320 -> 400px (README 표시 크기와 1:1)
    README 본문 폭이 약 900px이고 GIF를 2열 표에 넣어서 각 셀이 약 400px로
    표시된다. 320px 원본은 25% 확대 렌더링돼 작은 글자가 흐려지고 있었다.
    400px로 올려 1:1이 되게 했다.
    체감 차이는 작은 글자에서 나온다 - 탭 라벨(숄더프레스/레터럴),
    자동 추적/직접 조작 버튼, 카운터의 "/20". 이 GIF들이 증거로 쓰이는 이유가
    화면 속 숫자와 상태 배지라서 글자 선명도가 곧 값어치다.
    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
2026-09-09 docs: 서보 물리 배치 정정 — 모터가 헤드와 베이스에 나뉘어 있다
    README 캡션이 "헤드에 카메라, ST3215 2축(yaw·pitch)"라고 적혀 있어 두 모터가
    모두 헤드에 있는 것처럼 읽혔다. 실제로는 나뉘어 있다.
    헤드 카메라 + pitch(상하) 서보 ID=2
    베이스 yaw(좌우) 서보 ID=1 + UNO Q + 허브 + Bus Servo Adapter
    그래서 yaw는 헤드+기둥 전체를 돌리고 pitch는 헤드만 끄덕인다.
    docs/06에도 이 배치가 아예 없었다. 재조립 절차를 담은 문서인데 어느 통에 무엇이
    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
2026-09-09 docs: 케이블 경로 정정 — 기둥 안으로 지나고, 밖의 루프는 회전 여유분
    앞 커밋에서 사진만 보고 "케이블이 바깥으로 지나간다"고 적었는데 틀렸다.
    데이지체인은 기둥 안으로 지나고, 사진에 보이는 바깥 루프는 배선이 샌 게 아니라
    회전 여유를 주려고 일부러 빼둔 여유분이다.
    정리하거나 타이로 묶으면 yaw가 돌 때 케이블이 당겨지므로, 그러지 말라는
    주의를 함께 적었다.
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
